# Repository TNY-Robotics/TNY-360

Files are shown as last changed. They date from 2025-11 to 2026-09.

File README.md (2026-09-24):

> 🚀 TNY-360 V2 launches October 1, 2026.
> 
> The repository will be updated with the V2 release files and documentation at launch.

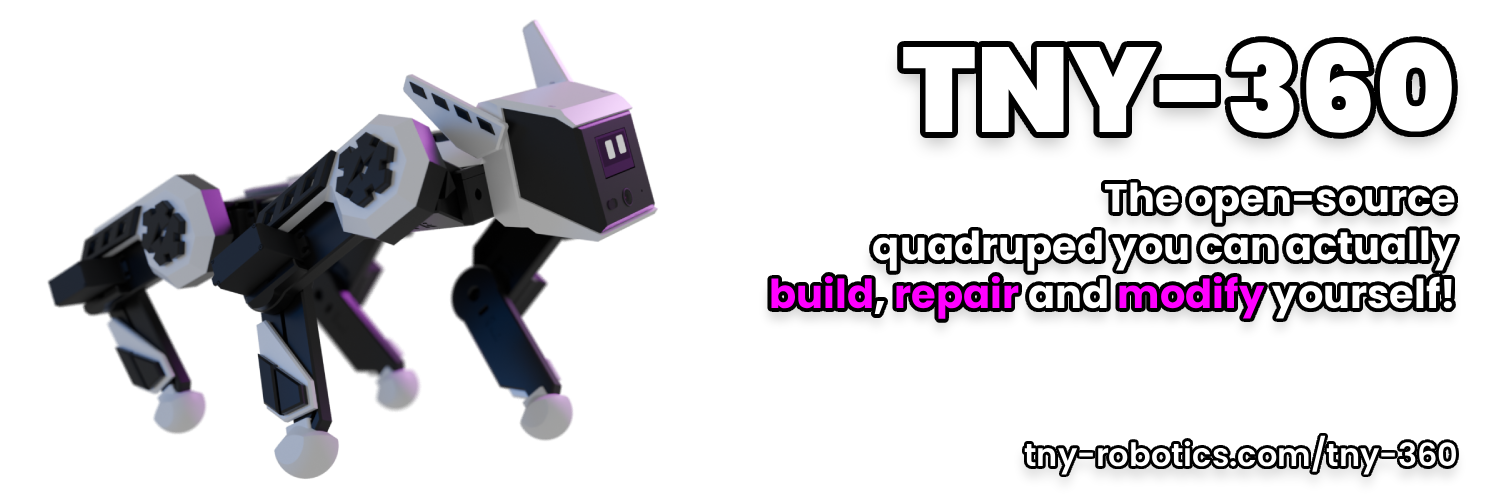
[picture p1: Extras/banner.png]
Banner


<div align="center">

# TNY-360 - Open-Source Robot Dog






**The open-source quadruped you can actually *build*, *repair* and *modify* yourself.**

[🌐 Website](https://tny-robotics.com/tny-360) • [📖 Documentation](https://tny-robotics.com/docs/tny-360/) • [💬 Discord](https://discord.gg/XGABkx5A4y) • [☕ Support Us](https://ko-fi.com/tnyrobotics)

</div>

<br />

# 🛠️ Want to build one?

<div align="center">

> ### **[👉 START HERE: The Official Step-by-Step Guide 👈](https://tny-robotics.com/docs/tny-360/practical-guide/sourcing)**
> *From ordering the first screw to assembling the last part, this guide covers it all.*

</div>

<br />

### 🗂️ Quick Links (For Advanced Makers)
If you know what you are doing and just want the raw files, here is your toolkit:

* 🛒 **[Bill of Materials (BOM)](https://tny-robotics.com/docs/tny-360/practical-guide/1.sourcing/)** - What to buy, tools needed, and where to find them.
* 📐 **[CAD & 3D Files](./CAD)** - Grab the `.STL` and `.3MF` files for your 3D printer.
* ⚡ **[PCB Designs (Gerbers)](./Electronics/PCBs)** - Files to order the custom PCBs used in the robot.
* 🧠 **[ESP32 Firmware](./Firmware)** - The ESP-IDF C++ firmware & drivers powering the robot.
* 🛠️ **[Servo Modding Tutorial](https://tny-robotics.com/docs/tny-360/anatomy/electronics/mg996r-mod)** - Learn the Op-Amp trick to get position-feedback on MG996R servos.

## ✨ Features

* 🧬 **Dual-Core Architecture:**<br> A segregated system using the ESP32-S3. Core 0 ("Reflex") runs a strict 200Hz kinematics/control loop, while Core 1 ("Brain") handles WebSockets, UI, and orchestration.
* 🔄 **Closed-Loop at 200Hz:**<br> We ditched blind PWM. The TNY-360 uses digital MG996R servos modified with a custom **Op-Amp buffer PCB** for noise-free, high-speed position feedback.
* ⚡ **Zero Cable Spaghetti:**<br> A fully modular hardware ecosystem. Dedicated PCBs (Control, Sensor, Brain, Power, etc.) communicate cleanly via standardized JST-PH cables.
* 🛠️ **Smart Auto-Calibration:**<br> Features mechanical endstops for assembly validation and runtime algorithms that compensate for backlash and actuator latency.
* 🧩 **STEM & Expansion Ready:**<br> Program the robot using [TNY-Coder](https://github.com/TNY-Robotics/TNY-Coder) (our block-based web app) or build custom hardware modules using the dorsal I2C/Power expansion port.
* 🔋 **Industrial Power:**<br> A custom 3S 18650 battery pack capable of 15A continuous discharge, featuring an integrated BMS and Fuse, for 1h+ of runtime.

## ⚙️ Hardware Specs

### 🧠 Core & Power
* **MCU:** ESP32-S3 N16R8 Module
* **Power:** 3S LiPo Battery (6x Samsung INR18650-25R)
* **Monitoring:** INA219 (Voltage/Current sensor)

### 🦵 Actuators
* **Legs:** 12x MG996R Servos *(Must be modified for analog feedback)*
* **Head:** 2x SG-90 Micro Servos (Ears)
* **Driver:** PCA9685 (16-Channel PWM)

### 📡 Sensors & I/O
* **Vision:** OV2640 Camera Module
* **Distance:** VL53L0X Time-of-Flight (Lidar)
* **Orientation:** MPU6050 6-axis IMU
* **Display:** SH1106 OLED (128x64)
* **Audio:** I2S MEMS Microphone + Speaker

---

## 📂 Repository Structure

* `BOM/` — **Bill of Materials.** Detailed lists of all components, PCBs, screws, and cables, with links.
* `CAD/` — **Hardware Source.** FreeCAD project files and ready-to-print STLs.
* `Electronics/PCBs/` — **PCB Designs.** Gerber files, BOMs, and Pick'n'Place for all PCBs.
* `Firmware/` — **Codebase.** PlatformIO project (C++/ESP-IDF).
* `Firmware/components/` — **Drivers.** Custom libraries for sensors/actuators.

## ☕ Support the Project

TNY-360 is, and will always be, 100% free and open-source. 

If you love the project, learned something new, or just want to help us build the next generation of affordable robots, consider supporting our R&D! Your tips help us buy prototyping materials (filament, PCBs, burned servos 😅) and keep the servers running.



*(Even if you can't donate, simply starring this repository or sharing it with a friend is already a massive support!)*

## 🤝 Contributing

We love contributions!
* **Code:** Please follow the ESP-IDF coding style.
* **Hardware:** Submit PRs with updated FreeCAD files or improvements.
* Found a bug? [Open an Issue](https://github.com/TNY-Robotics/TNY-360/issues).

## 📄 License & Authors

**TNY-360** is maintained by the [TNY Robotics Team](https://tny-robotics.com).

Licensed under **CC BY-NC-SA 4.0**.<br>
*You are free to share and adapt this material for non-commercial purposes, as long as you provide attribution and share alike.*



Need help? Contact us [by mail](mailto:contact@tny-robotics.com) or join our [Discord](https://discord.gg/XGABkx5A4y).

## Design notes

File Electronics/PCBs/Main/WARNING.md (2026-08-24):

# Warning : Inverted Diode

The D3 diode (between the fuse and the USB-C connector) is inverted in the schematics and the PCB.

Do not solder the diode, or place it "upside-down" to avoid any problem.

*sorry for the inconvenience, V2 of the robot is coming soon to fix this problem*

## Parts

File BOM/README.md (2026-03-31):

# Bill Of Material

Here's the raw List of components you need to build your own TNY-360 robot.

You can also find a more user-friendly version of this list on the [TNY-360 Documentation](https://tny-robotics.com/docs/tny-360/practical-guide/sourcing/) as well as guides and manuals to help you source, print, assemble, and set up your TNY-360!

- List of [Screws and Inserts](./Screws.md)

- List of [Cables](./Cables.md)

- List of [PCBs](./PCBs.md)

- List of [Components](./Components.md)

*Have fun building your robot!*

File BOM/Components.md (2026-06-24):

# Components

Here's a list of all the components needed to build your TNY-360, and their links!

### Assembly guide

To learn how to fully assemble you TNY-360, check out the [TNY-360 Documentation](http://tny-robotics.com/docs/tny-360/practical-guide/sourcing/). A more user-friendly list of all the components needed is also available here. 

| Type | Description | Quantity | Location | Link |
| :--- | :--- | :---: | :--- | :--- |
| Step down | DC-DC 300W 20A Buck Converter | 1 | Torso Back | [Click here](https://s.click.aliexpress.com/e/_c3atP8dn) |
| Step down | DC-DC 5V 3A Converter | 1 | Mount PCB | [Click here](https://fr.aliexpress.com/item/1005008678729834.html) \[5V\] |
| | | | | |
| VL53L0X | Laser depth sensor | 1 | Visor | [Click here](https://s.click.aliexpress.com/e/_c4LPbeMT) \[0-200CM\] |
| SH1106 | OLED Screen 64x128 | 1 | Visor | [Click here](https://s.click.aliexpress.com/e/_c4POAdYX) \[WHITE\] |
| TTP223 | Touch sensor | 2 | Visor | [Click here](https://fr.aliexpress.com/item/1005006087171183.html) |
| OV2640 | HD Camera  120° 75mm | 1 | Visor | [Click here](https://s.click.aliexpress.com/e/_c3eXa4EP) \[120°/75mm\] |
| I2S Mic.  | I2S Microphone | 1 | Visor | [Click here](https://s.click.aliexpress.com/e/_c3CFAo5V) |
| Speaker | 2W 8Ω Speaker (25mm x 35mm) | 1 | Head | [Click here](https://fr.aliexpress.com/item/1005008626624201.html) \[5PCS 8Ω 2W\] |
| | | | | |
| SG90 | 0.9kg.cm servomotor | 2 | Head | [Click here](https://s.click.aliexpress.com/e/_c4PiVQKP) \[180°\] |
| MG996R | 12kg.cm servomotor | 12 | Torso / Legs | [Click here](https://s.click.aliexpress.com/e/_c3QXPU2f) \[180°\] |
| | | | | |
| MPU6050 | 6 axis accelerometer & gyroscope | 1 | Torso Center | [Click here](https://s.click.aliexpress.com/e/_c4LXGDrH) |
| Switches  | Tactile switches 6x6x5 mm | 4 | Feet | [Click here](https://s.click.aliexpress.com/e/_c4koO1EL) \[6x6x5mm\] |
| Antenna | Wi-Fi/Bluetooth 2.4Ghz antenna | 1 | Head | [Click here](https://s.click.aliexpress.com/e/_c3wCvBLz) \[FPC-IPX1/5cm] |

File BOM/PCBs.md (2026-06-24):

# PCBs

Here's a list of all PCBs needed to build your TNY-360. You can find all design files in the [GitHub repository](https://github.com/TNY-Robotics/TNY-360/tree/main/Electronics/PCBs).

### Assembly guide

To learn how to fully assemble you TNY-360, check out the [TNY-360 Documentation](http://tny-robotics.com/docs/tny-360/practical-guide/sourcing/). A more user-friendly list of all the PCBs needed is also available here.

### PCBs list

| PCB | Purpose | Quantity | Files |
| --- | --- | :---: | --- |
| Main Board | Robot brain and main controller | 1 | [GitHub PCB Files](https://github.com/TNY-Robotics/TNY-360/tree/main/Electronics/PCBs/Main) |
| Analog Reader | Sensor interface board | 1 | [GitHub PCB Files](https://github.com/TNY-Robotics/TNY-360/tree/main/Electronics/PCBs/Analog%20Reader) |
| Motor Driver  | Motor control board | 1 | [GitHub PCB Files](https://github.com/TNY-Robotics/TNY-360/tree/main/Electronics/PCBs/Motor%20Driver) |
| Power Board | Power distribution | 1 | [GitHub PCB Files](https://github.com/TNY-Robotics/TNY-360/tree/main/Electronics/PCBs/Power) |
| Paw Board | Legs multiplexing and power management | 2 | [GitHub PCB Files](https://github.com/TNY-Robotics/TNY-360/tree/main/Electronics/PCBs/Paw) |
| Plug Board | Universal Mount interface | 1 | [GitHub PCB Files](https://github.com/TNY-Robotics/TNY-360/tree/main/Electronics/PCBs/Universal%20Mount) |
| Servo Board | Custom MG996R servo modification board | 12 | [GitHub PCB Files](https://github.com/TNY-Robotics/TNY-360/tree/main/Electronics/PCBs/Servomotor) |

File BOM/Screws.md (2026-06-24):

# Screws & Inserts

Here's a list of all screws and inserts needed to build your TNY-360.

A complete kit of M2.5 Screws and Inserts is also linked below for easier sourcing, instead of buying each screws/inserts independently.

### Assembly guide

To learn how to fully assemble you TNY-360, check out the [TNY-360 Documentation](http://tny-robotics.com/docs/tny-360/practical-guide/sourcing/). A more user-friendly list of all the screws and inserts needed is also available here.

### Screws 

| Type | Length | Quantity | Location | Link |
| :--- | :----- | :---: | :--- | :---: |
| M1.4 | 5 mm | 32 | Shoulder & Knee Servo Disk  | [Click here](https://s.click.aliexpress.com/e/_c3CWv1Vp) |
| | | | | |
| M2.5 | 4 mm | 2 | Torso - PCB Motor Driver | [Click here](https://s.click.aliexpress.com/e/_c3p0AJO3) |
| M2.5 | 4 mm | 2 | Torso - PCB Analog Reader | [Click here](https://s.click.aliexpress.com/e/_c3p0AJO3) |
| M2.5 | 4 mm | 2 | Torso - PCB IMU | [Click here](https://s.click.aliexpress.com/e/_c3p0AJO3) |
| M2.5 | 4 mm | 2 | Torso - PCB Paw Boards | [Click here](https://s.click.aliexpress.com/e/_c3p0AJO3) |
| M2.5 | 4 mm | 4 | Torso - DC-DC Converter | [Click here](https://s.click.aliexpress.com/e/_c3p0AJO3) |
| M2.5 | 10 mm  | 12 | Torso - Top / Bottom screws | [Click here](https://s.click.aliexpress.com/e/_c3p0AJO3) |
| M2.5 | 6 mm | 4 | Torso - Front | [Click here](https://s.click.aliexpress.com/e/_c3p0AJO3) |
| M2.5 | 6 mm | 4 | Torso - Back | [Click here](https://s.click.aliexpress.com/e/_c3p0AJO3) |
| M2.5 | 6 mm | 4 | Torso - Battery | [Click here](https://s.click.aliexpress.com/e/_c3p0AJO3) |
| | | | | |
| M2.5 | 4 mm | 4 | Head - Top | [Click here](https://s.click.aliexpress.com/e/_c3p0AJO3) |
| M2.5 | 4 mm | 4 | Head - Bottom | [Click here](https://s.click.aliexpress.com/e/_c3p0AJO3) |
| M2.5 | 4 mm | 2 | Head - Face Plate | [Click here](https://s.click.aliexpress.com/e/_c3p0AJO3) |
| M2.5 | 4 mm | 4 | Head - PCB | [Click here](https://s.click.aliexpress.com/e/_c3p0AJO3) |
| | | | | |
| M2.5 | 6 mm | 8 | Shoulders - Top | [Click here](https://s.click.aliexpress.com/e/_c3p0AJO3) |
| M2.5 | 4 mm | 2 | Ears - Main Screw | [Click here](https://s.click.aliexpress.com/e/_c3p0AJO3) |
| M2.5 | 4 mm | 3 | Back - PCB | [Click here](https://s.click.aliexpress.com/e/_c3p0AJO3) |
| M2.5 | 4 mm | 4 | Back - Cover | [Click here](https://s.click.aliexpress.com/e/_c3p0AJO3) |
| | | | | |
| M2.5 | 6 mm | 4 | Mount - Cover | [Click here](https://s.click.aliexpress.com/e/_c3p0AJO3) |
| M2.5 | 6 mm | 4 | Mount - Attachment | [Click here](https://s.click.aliexpress.com/e/_c3p0AJO3) |
| M2.5 | 4 mm | 2 | Mount - PCB | [Click here](https://s.click.aliexpress.com/e/_c3p0AJO3) |
| | | | | |
| M2.5 | 4 mm | 6 | Battery - PCB | [Click here](https://s.click.aliexpress.com/e/_c3p0AJO3) |
| M2.5 | 4 mm | 6 | Battery - Cover | [Click here](https://s.click.aliexpress.com/e/_c3p0AJO3) |

### Inserts 

| Type | Length | Quantity | Location | Link |
| :--- | :----- | :---: | :--- | :---: |
| M2.5 | 2 mm | 2 | Torso - PCB Motor Driver | [Click here](https://fr.aliexpress.com/item/1005007653131713.html) |
| M2.5 | 2 mm | 2 | Torso - PCB Analog Reader | [Click here](https://fr.aliexpress.com/item/1005007653131713.html) |
| M2.5 | 2 mm | 2 | Torso - PCB IMU | [Click here](https://fr.aliexpress.com/item/1005007653131713.html) |
| M2.5 | 2 mm | 2 | Torso - PCB Paw Boards | [Click here](https://fr.aliexpress.com/item/1005007653131713.html) |
| M2.5 | 2 mm | 4 | Torso - DC-DC Converter | [Click here](https://fr.aliexpress.com/item/1005007653131713.html) |
| M2.5 | 6 mm | 12 | Torso - Top / Bottom screws | [Click here](https://fr.aliexpress.com/item/1005007653131713.html) |
| M2.5 | 4 mm | 4 | Torso - Front | [Click here](https://fr.aliexpress.com/item/1005007653131713.html) |
| M2.5 | 4 mm | 4 | Torso - Back | [Click here](https://fr.aliexpress.com/item/1005007653131713.html) |
| M2.5 | 2 mm | 4 | Torso - Battery | [Click here](https://fr.aliexpress.com/item/1005007653131713.html) |
| | | | | |
| M2.5 | 2 mm | 4 | Head - Top | [Click here](https://fr.aliexpress.com/item/1005007653131713.html) |
| M2.5 | 2 mm | 4 | Head - Bottom | [Click here](https://fr.aliexpress.com/item/1005007653131713.html) |
| M2.5 | 2 mm | 2 | Head - Face Plate | [Click here](https://fr.aliexpress.com/item/1005007653131713.html) |
| M2.5 | 2 mm | 4 | Head - PCB | [Click here](https://fr.aliexpress.com/item/1005007653131713.html) |
| | | | | |
| M2.5 | 2 mm | 8 | Shoulders - Top | [Click here](https://fr.aliexpress.com/item/1005007653131713.html) |
| M2.5 | 2 mm | 2 | Ears - Main Screw | [Click here](https://fr.aliexpress.com/item/1005007653131713.html) |
| M2.5 | 2 mm | 3 | Back - PCB | [Click here](https://fr.aliexpress.com/item/1005007653131713.html) |
| M2.5 | 2 mm | 4 | Back - Cover | [Click here](https://fr.aliexpress.com/item/1005007653131713.html) |
| | | | | |
| M2.5 | 4 mm | 4 | Mount - Cover | [Click here](https://fr.aliexpress.com/item/1005007653131713.html) |
| M2.5 | 4 mm | 4 | Mount - Attachment | [Click here](https://fr.aliexpress.com/item/1005007653131713.html) |
| M2.5 | 2 mm | 2 | Mount - PCB | [Click here](https://fr.aliexpress.com/item/1005007653131713.html) |
| | | | | |
| M2.5 | 2 mm | 6 | Battery - PCB | [Click here](https://fr.aliexpress.com/item/1005007653131713.html) |
| M2.5 | 2 mm | 6 | Battery - Cover | [Click here](https://fr.aliexpress.com/item/1005007653131713.html) |

### Total 

| Type | Quantity | Link |
| :--- | :---: | --- |
| M1.4 Screw - 5 mm  | 32 | [Click here](https://s.click.aliexpress.com/e/_c3CWv1Vp) |
| | | |
| M2.5 Screw - 4 mm  | 49 | [Click here](https://s.click.aliexpress.com/e/_c3p0AJO3) |
| M2.5 Screw - 6 mm  | 28 | [Click here](https://s.click.aliexpress.com/e/_c3p0AJO3) |
| M2.5 Screw - 10 mm | 12 | [Click here](https://s.click.aliexpress.com/e/_c3p0AJO3) |
| | | |
| M2.5 Insert - 2 mm | 61 | [Click here](https://fr.aliexpress.com/item/1005007653131713.html) |
| M2.5 Insert - 4 mm | 16 | [Click here](https://fr.aliexpress.com/item/1005007653131713.html) |
| M2.5 Insert - 6 mm | 12 | [Click here](https://fr.aliexpress.com/item/1005007653131713.html) |

### Complete kit

To simplify Screws and Inserts sourcing, you can alternatively buy only one complete kit of M2.5 screws and inserts.

* Link to the [Screws / Inserts Kit](https://fr.aliexpress.com/item/1005007830491580.html).

Please check that you selected the `M2.5 500pcs` version before ordering.

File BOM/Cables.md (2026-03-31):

# Cables

Here's a list of all cables needed to wire up your TNY-360.

A complete kit of JST-PH wires is also linked below for easier sourcing, instead of buying each cable independently.

### Assembly guide

To learn how to fully assemble you TNY-360, check out the [TNY-360 Documentation](https://tny-robotics.com/docs/tny-360/practical-guide/sourcing/). A more user-friendly list of all the cables needed is also available here.

| Type | Pins | Length | Quantity | Location | Link |
| :--- | :--: | :----- | :---: | :--- | :--- |
| JST-PH |  3 | 100 mm | 4 | Motor Driver -> Paw Board | [Click here](https://s.click.aliexpress.com/e/_c3BIp6Ux) |
| JST-PH |  2 | 100 mm | 1 | Motor Driver -> Main Board | [Click here](https://s.click.aliexpress.com/e/_c3BIp6Ux) |
| JST-PH |  5 | 100 mm | 1 | Motor Driver -> Main Board | [Click here](https://s.click.aliexpress.com/e/_c3BIp6Ux) |
| JST-PH |  4 | 100 mm | 4 | Analog Reader -> Paw Board | [Click here](https://s.click.aliexpress.com/e/_c3BIp6Ux) |
| JST-PH |  7 | 100 mm | 1 | Analog Reader -> Main Board | [Click here](https://s.click.aliexpress.com/e/_c3BIp6Ux) |
| JST-PH (PIGTAIL) |  4 | 200 mm | 1 | IMU -> Paw Board | [Click here](https://s.click.aliexpress.com/e/_c44pILQb) |
| JST-PH |  4 | 200 mm | 2 | Plug Board -> Power & Main Board | [Click here](https://s.click.aliexpress.com/e/_c3BIp6Ux) |
| JST-PH |  2 | 200 mm | 2 | Plug Board -> Power & Main Board | [Click here](https://s.click.aliexpress.com/e/_c3BIp6Ux) |
| JST-PH (PIGTAIL) |  4 | 50 mm  | 1 | SH1106 -> Main Board | [Click here](https://s.click.aliexpress.com/e/_c44pILQb) |
| JST-PH (PIGTAIL) |  3 | 50 mm  | 2 | TTP23 -> Main Board | [Click here](https://s.click.aliexpress.com/e/_c44pILQb) |
| JST-PH (PIGTAIL) |  4 | 50 mm  | 1 | VL53L0X -> Main Board | [Click here](https://s.click.aliexpress.com/e/_c44pILQb) |
| JST-PH (PIGTAIL) |  5 | 50 mm  | 1 | I2S Mic. -> Main Board | [Click here](https://s.click.aliexpress.com/e/_c44pILQb) |
| JST-PH (PIGTAIL) |  2 | 450 mm | 4 | Contact Switch -> Paw Board | [Click here](https://s.click.aliexpress.com/e/_c44pILQb) |
| JST-XH (PIGTAIL) |  4 | 100 mm | 8 | Shoulder Servo -> Paw Board | [Click here](https://s.click.aliexpress.com/e/_c3WRxkg7) |
| JST-XH (PIGTAIL) |  4 | 300 mm | 4 | Leg Servo -> Paw Board | [Click here](https://s.click.aliexpress.com/e/_c3WRxkg7) |
| JST-XH (PIGTAIL) |  4 | 300 mm | 4 | Leg Servo -> Paw Board | [Click here](https://s.click.aliexpress.com/e/_c3WRxkg7) |
| 16 AWG Wire | | 100 mm | 3 | DC-DC Converter -> Paw Board | [Click here](https://fr.aliexpress.com/item/1005006614755156.html) |

### Connectors
| Type | Quantity | Link |
| --- | --- | --- |
| Ring Crimp Connector | 6 | [Click here](https://s.click.aliexpress.com/e/_c2yxJCd5) |
| Dupont Connector | 4 | None - Use the ones from the MG996R motors :) |

### Complete kit

To simplify cable sourcing, you can alternatively buy only one JST-PH cable kit, and some JST-XH pigtail cables.

* Link to the [JST-PH Cables Kit](https://s.click.aliexpress.com/e/_c3AtPZ9h).
* Link to the [Dupont Connector Kit](https://fr.aliexpress.com/item/4001063470283.html);
* Link to the [JST-XH Pigtail Cables](https://s.click.aliexpress.com/e/_c3WRxkg7).

Please check that you selected the `XH-2.54mm version (4P)` before ordering.

### About the SH1106, TTP23, VL53L0X and I2S Mic. cables

Since these cables are going to be soldered directly on the component, you can buy a 100mm cable and cut it in half to make 2x 50mm pigtail cables. This reduces the number of cables to order.

### About the contact switch cable

The contact switch cable should end with a 3-pin Dupont connector (the standard 2.54mm arduino connectors), with the middle pin empty.

No such cable (JST-PH 2-Pins to 2.54 mm Dupont 3 Pins) exists on the web, so you will probably have to make it yourself. A complete guide on how to create that cable is available *(or will be available)* on the [TNY-360 Documentation](https://tny-robotics.com/docs/tny-360).

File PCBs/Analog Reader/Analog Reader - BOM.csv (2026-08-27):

No. | Quantity | Comment | Designator | Footprint | Value | Manufacturer Part | Manufacturer | Supplier Part | Supplier
1 | 1 | 74HC4067PW,118 | 74HC4067 | TSSOP-24_L7.8-W4.4-P0.65-LS6.4-BL |  | 74HC4067PW,118 | Nexperia(安世) | C179326 | LCSC
2 | 1 | HX PZ2.0-2x5P TP | BRAIN | CONN-SMD_HX-PZ2.0-2X5P-TP |  | HX PZ2.0-2x5P TP | hanxia(韩下) | C32713243 | LCSC
3 | 16 | 1uF | C1,C2,C3,C4,C5,C6,C7,C8,C9,C10,C11,C12,C13,C14,C15,C16 | C0603 | 1uF | CL10A105KB8NNNC | SAMSUNG(三星) | C15849 | LCSC
4 | 2 | 100nF | C-74HC1,C-OPA1 | C0603 | 100nF | CC0603KRX7R9BB104 | YAGEO(国巨) | C14663 | LCSC
5 | 1 | XL-0807RGBC-2812B | LED | LED-SMD_4P-L2.0-W1.8_XL-0807RGBC-WS2812B |  | XL-0807RGBC-2812B | XINGLIGHT(成兴光) | C3646929 | LCSC
6 | 2 | HX PZ2.0-2x4P TP | LEFT,RIGHT | CONN-SMD_HX-PZ2.0-2X4P-TP |  | HX PZ2.0-2x4P TP | hanxia(韩下) | C32713242 | LCSC
7 | 1 | AD8628ARTZ(UMW) | OP-AMP1 | SOT-23-5_L2.9-W1.6-P0.95-LS2.8-BR |  | AD8628ARTZ(UMW) | UMW(友台半导体) | C32713098 | LCSC
8 | 16 | 1kΩ | R1,R2,R3,R4,R5,R6,R7,R8,R9,R10,R11,R12,R13,R14,R15,R16 | R0603 | 1kΩ | 0603WAF1001T5E | UNI-ROYAL(厚声) | C21190 | LCSC
9 | 1 | 220Ω | ROPA1 | R0603 | 220Ω | 0603WAF2200T5E | UNI-ROYAL(厚声) | C22962 | LCSC

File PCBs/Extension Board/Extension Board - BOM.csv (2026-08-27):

No. | Quantity | Comment | Designator | Footprint | Value | Manufacturer Part | Manufacturer | Supplier Part | Supplier
1 | 1 | ZX-PH2.0-LT4P | EXT | CONN-SMD_4P-P2.00_MEGASTAR_ZX-PH2.0-LT4P |  | ZX-PH2.0-LT4P | Megastar(兆星) | C7429700 | LCSC
2 | 1 | ZX-PHB2.0-2-3PLT | POWER | CONN-SMD_6P-P2.00_ZX-PHB2.0-2-3PLT |  | ZX-PHB2.0-2-3PLT | Megastar(兆星) | C19078801 | LCSC
3 | 1 | 1kΩ | R1 | R0603 | 1kΩ | 0603WAF1001T5E | UNI-ROYAL(厚声) | C21190 | LCSC
4 | 1 | AMS1117-3.3 | U1 | SOT-223-3_L6.5-W3.4-P2.30-LS7.0-BR |  | AMS1117-3.3 | Advanced Monolithic Systems | C6186 | LCSC

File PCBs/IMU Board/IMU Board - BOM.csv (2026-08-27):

No. | Quantity | Comment | Designator | Footprint | Value | Manufacturer Part | Manufacturer | Supplier Part | Supplier
1 | 1 | PZ200-2-04-S | BRAIN | HDR-SMD_8P-P2.00-V-M-R2-C4-LS6.5_PZ200-2-04-S |  | PZ200-2-04-S | HCTL(华灿天禄) | C3294483 | LCSC
2 | 2 | 100nF | C1,C2 | C0603 | 100nF | CC0603KRX7R9BB104 | YAGEO(国巨) | C14663 | LCSC
3 | 1 | XL-0807RGBC-2812B | LED | LED-SMD_4P-L2.0-W1.8_XL-0807RGBC-WS2812B |  | XL-0807RGBC-2812B | XINGLIGHT(成兴光) | C3646929 | LCSC
4 | 1 | LSM6DSLTR | LSM6DS3 | LGA-14_L3.0-W2.5-P0.50-TL |  | LSM6DSLTR | ST(意法半导体) | C126672 | LCSC

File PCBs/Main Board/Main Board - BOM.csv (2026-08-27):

No. | Quantity | Comment | Designator | Footprint | Value | Manufacturer Part | Manufacturer | Supplier Part | Supplier
1 | 2 | AMS1117-3.3 | AMS3.3,AMS3.3ESP | SOT-223-3_L6.5-W3.4-P2.30-LS7.0-BR |  | AMS1117-3.3 | Advanced Monolithic Systems | C6186 | LCSC
2 | 1 | AFA07-S14FCA-00 | BACKBONE | FPC-SMD_P1.00-14P_LCS-XJ-H2.5 |  | AFA07-S14FCA-00 | JS(钜硕电子) | C262720 | LCSC
3 | 2 | 1nF | C1,C2 | C0603 | 1nF | CL10B102KB8NNNC | SAMSUNG(三星) | C1588 | LCSC
4 | 2 | 1uF | C3,CUPEN | C0603 | 1uF | CL10A105KB8NNNC | SAMSUNG(三星) | C15849 | LCSC
5 | 1 | 470uF | C4 | CAP-SMD_BD6.3-L6.6-W6.6-FD | 470uF | RVT1A471M0607 | ROQANG(容强) | C335982 | LCSC
6 | 7 | 100nF | CA,CAVDD1,CB,CCAM14,CCSI-RST,CDVDD1,CESP1 | C0603 | 100nF | CC0603KRX7R9BB104 | YAGEO(国巨) | C14663 | LCSC
7 | 1 | FPC-05F-24PH20 | CAMERA | FPC-SMD_24P-P0.50_FPC-05F-24PH20 |  | FPC-05F-24PH20 | XUNPU(讯普) | C2856805 | LCSC
8 | 1 | 10nF | CASIG | C0603 | 10nF | 0603B103K500NT | FH(风华) | C57112 | LCSC
9 | 4 | 10uF | CAVDD2,CCH340,CDVDD2,CESP2 | C0603 | 10uF | CL10A106MA8NRNC | SAMSUNG(三星) | C96446 | LCSC
10 | 1 | 15pF | CCAM8 | C0603 | 15pF | CL10C150JB8NNNC | SAMSUNG(三星) | C1644 | LCSC
11 | 1 | CH340C | CH340C | SOP-16_L10.0-W3.9-P1.27-LS6.0-BL |  | CH340C | WCH(南京沁恒) | C84681 | LCSC
12 | 2 | SS34 | D1,D2 | SMA_L4.3-W2.6-LS5.2-RD |  | SS34 | MDD(辰达半导体) | C8678 | LCSC
13 | 1 | ESP32-S3-WROOM-1U-N16R8 | ESP32-S3 | WIRELM-SMD_ESP32-S3-WROOM-1U |  | ESP32-S3-WROOM-1U-N16R8 | ESPRESSIF(乐鑫) | C3013946 | LCSC
14 | 2 | BLM18PG121SN1D | L1,L2 | L0603 |  | BLM18PG121SN1D | muRata(村田) | C14709 | LCSC
15 | 1 | XL-0807RGBC-2812B | LED | LED-SMD_4P-L2.0-W1.8_XL-0807RGBC-WS2812B |  | XL-0807RGBC-2812B | XINGLIGHT(成兴光) | C3646929 | LCSC
16 | 1 | NS4168 | NS4168 | ESOP-8_L4.9-W3.9-P1.27-LS6.0-BL-EP |  | NS4168 | Nsiway(纳芯威) | C910588 | LCSC
17 | 2 | S8050 J3Y(RANGE:200-350) | QDTR1,QRTS1 | SOT-23-3_L3.0-W1.7-P0.95-LS2.9-BR |  | S8050 J3Y(RANGE:200-350) | CJ(江苏长电/长晶) | C2146 | LCSC
18 | 4 | 10kΩ | R1,RDTR1,RRTS1,RUPEN | R0603 | 10kΩ | 0603WAF1002T5E | UNI-ROYAL(厚声) | C25804 | LCSC
19 | 1 | 1kΩ | RCAM17 | R0603 | 1kΩ | 0603WAF1001T5E | UNI-ROYAL(厚声) | C21190 | LCSC
20 | 1 | 33Ω | RMIC | R0603 | 33Ω | 0603WAF330JT5E | UNI-ROYAL(厚声) | C23140 | LCSC
21 | 1 | 4.7kΩ | RRST | R0603 | 4.7kΩ | 0603WAF4701T5E | UNI-ROYAL(厚声) | C23162 | LCSC
22 | 4 | 2.2kΩ | RUPFA,RUPFL,RUPSA,RUPSL | R0603 | 2.2kΩ | 0603WAF2201T5E | UNI-ROYAL(厚声) | C4190 | LCSC
23 | 2 | 5.1kΩ | RUSB1,RUSB2 | R0402 | 5.1kΩ | 0402WGF5101TCE | UNI-ROYAL(厚声) | C25905 | LCSC
24 | 1 | HC-1.25-2PWT | SPKR | CONN-SMD_2P-P1.25-HC-1.25-2PWT |  | HC-1.25-2PWT | HCTL(华灿天禄) | C2845379 | LCSC
25 | 2 | TS-1088-AR02016 | SW_0,SW_EN | SW-SMD_L3.9-W3.0-P4.45 |  | TS-1088-AR02016 | XUNPU(讯普) | C720477 | LCSC
26 | 1 | TXB0104RUTR | TXB0104 | UQFN-12_L2.0-W1.7-P0.40-BL |  | TXB0104RUTR | TI(德州仪器) | C105266 | LCSC
27 | 1 | TYPE-C16PIN | USB | USB-C-SMD_TYPE-C16PIN |  | TYPE-C16PIN | SHOU HAN(首韩) | C393939 | LCSC
28 | 1 | USBLC6-2SC6 | USBLC6 | SOT-23-6_L2.9-W1.6-P0.95-LS2.8-BL |  | USBLC6-2SC6 | ST(意法半导体) | C7519 | LCSC
29 | 1 | AFA07-S08FCA-00 | VISOR | FPC-SMD_8P-P1.00_LCS-XJ |  | AFA07-S08FCA-00 | JS(钜硕电子) | C262714 | LCSC
30 | 1 | XC6206-1.2V | XC6206-1.2 | SOT-23-3_L3.0-W1.6-P1.90-LS2.8-BR |  | XC6206-1.2V | YONGYUTAI(永裕泰) | C49446790 | LCSC
31 | 1 | XC6206-2.8V | XC6206-2.8 | SOT-23-3_L2.9-W1.6-P1.90-LS2.8-BR |  | XC6206-2.8V | YONGYUTAI(永裕泰) | C2892669 | LCSC

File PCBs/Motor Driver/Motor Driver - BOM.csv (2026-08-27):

No. | Quantity | Comment | Designator | Footprint | Value | Manufacturer Part | Manufacturer | Supplier Part | Supplier
1 | 3 | HX PZ2.0-2x4P TP | BRAIN,LEFT,RIGHT | CONN-SMD_HX-PZ2.0-2X4P-TP |  | HX PZ2.0-2x4P TP | hanxia(韩下) | C32713242 | LCSC
2 | 2 | 100nF | CLS1,CPCA1 | C0603 | 100nF | CC0603KRX7R9BB104 | YAGEO(国巨) | C14663 | LCSC
3 | 1 | XL-0807RGBC-2812B | LED | LED-SMD_4P-L2.0-W1.8_XL-0807RGBC-WS2812B |  | XL-0807RGBC-2812B | XINGLIGHT(成兴光) | C3646929 | LCSC
4 | 1 | PCA9306DCUR | PCA9306 | SSOP-8_L2.0-W2.3-P0.50-LS3.1-BR |  | PCA9306DCUR | TI(德州仪器) | C33196 | LCSC
5 | 1 | PCA9685PW,118 | PCA9685 | TSSOP-28_L9.7-W4.4-P0.65-LS6.4-TL | - | PCA9685PW,118 | NXP(恩智浦) | C2678753 | LCSC
6 | 16 | 220Ω | R1,R2,R3,R4,R5,R6,R7,R8,R9,R10,R11,R12,R13,R14,R15,R16 | R0603 | 220Ω | 0603WAF2200T5E | UNI-ROYAL(厚声) | C22962 | LCSC
7 | 1 | 200kΩ | R-LS1 | R0603 | 200kΩ | 0603WAF2003T5E | UNI-ROYAL(厚声) | C25811 | LCSC
8 | 2 | 2.2kΩ | RUP1,RUP2 | R0603 | 2.2kΩ | 0603WAF2201T5E | UNI-ROYAL(厚声) | C4190 | LCSC

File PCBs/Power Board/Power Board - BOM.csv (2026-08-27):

No. | Quantity | Comment | Designator | Footprint | Value | Manufacturer Part | Manufacturer | Supplier Part | Supplier
1 | 1 | XT60PB-M.G.Y | BAT | CONN-TH_XT60PB-M |  | XT60PB-M.G.Y | AMASS(艾迈斯) | C19268037 | LCSC
2 | 1 | 1uF | C1 | C0603 | 1uF | CL10A105KB8NNNC | SAMSUNG(三星) | C15849 | LCSC
3 | 1 | XF-508PVS-B | F1 | FUSE-SMD_4P-L16.0-W6.7-P9.92 |  | XF-508PVS-B | XFCN(兴飞) | C17700142 | LCSC
4 | 1 | WAFER-PH2.0-2PLB | I2C | CONN-TH_2P-P2.00_XUNPU_WAFER-PH2.0-2PLB |  | WAFER-PH2.0-2PLB | XUNPU(讯普) | C3029431 | LCSC
5 | 1 | INA219BIDR | INA219 | SOIC-8_L5.0-W4.0-P1.27-LS6.1-BL |  | INA219BIDR | TI(德州仪器) | C2155799 | LCSC
6 | 1 | 78L05G-AB3-R | LDO | SOT-89-3_L4.5-W2.5-P1.50-LS4.2-BR |  | 78L05G-AB3-R | UTC(友顺) | C71136 | LCSC
7 | 1 | XT30UPB-F30.G.Y | OUT | CONN-TH_XT30UPB-F |  | XT30UPB-F30.G.Y | AMASS(艾迈斯) | C108769 | LCSC
8 | 2 | LWP3005AD5 | Q1,Q2 | TDSON-8_L5.9-W5.2-P1.27-BL-1 |  | LWP3005AD5 | Lewa Micro(乐瓦微电子) | C54740917 | LCSC
9 | 1 | 100kΩ | R1 | R0603 | 100kΩ | 0603WAF1003T5E | UNI-ROYAL(厚声) | C25803 | LCSC
10 | 1 | 10kΩ | R2 | R0603 | 10kΩ | 0603WAF1002T5E | UNI-ROYAL(厚声) | C25804 | LCSC
11 | 1 | 2mΩ | Rsns | R2512 | 2mΩ | FRM252WFR002TN | FOJAN(富捷) | C7467245 | LCSC
12 | 1 | MST-12D18G4 SPDT Slide Switch | SW | SW-SMD_MST-12D18G4-SPDT-SLIDE-SWITCH |  | MST-12D18G4 SPDT Slide Switch | SHOU HAN(首韩) | C49023767 | LCSC

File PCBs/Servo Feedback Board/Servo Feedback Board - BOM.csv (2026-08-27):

No. | Quantity | Comment | Designator | Footprint | Value | Manufacturer Part | Manufacturer | Supplier Part | Supplier
1 | 1 | 100nF | C1 | C0402 | 100nF | CL05B104KO5NNNC | SAMSUNG(三星) | C1525 | LCSC
2 | 1 | AD8628ARTZ(UMW) | OP-AMP | SOT-23-5_L2.9-W1.6-P0.95-LS2.8-BR |  | AD8628ARTZ(UMW) | UMW(友台半导体) | C32713098 | LCSC

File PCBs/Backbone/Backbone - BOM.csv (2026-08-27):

No. | Quantity | Comment | Designator | Footprint | Value | Manufacturer Part | Manufacturer | Supplier Part | Supplier
1 | 1 | HX PM2.0-2x5P TP | AR | HDR-SMD_10P-P2.00-V-F-R2-C5-LS6.2-1 |  | HX PM2.0-2x5P TP | hanxia(韩下) | C41397150 | LCSC
2 | 6 | HX PM2.0-2x4P TP | AR-L,AR-R,IMU,MD,MD-L,MD-R | HDR-SMD_HX-PM2.0-2X4P-TP |  | HX PM2.0-2x4P TP | hanxia(韩下) | C41397149 | LCSC
3 | 12 | WAFER-XH2.54-4PLB | BL-HP,BL-HR,BL-KP,BR-HP,BR-HR,BR-KP,FL-HP,FL-HR,FL-KP,FR-HP,FR-HR,FR-KP | CONN-SMD_4P-P2.50_XUNPU_WAFER-XH2.54-4PLB |  | WAFER-XH2.54-4PLB | XUNPU(讯普) | C3029469 | LCSC
4 | 4 | WAFER-SH1.0-3PLB | BL-SW,BR-SW,FL-SW,FR-SW | CONN-SMD_3P-P1.00_XUNPU_WAFER-SH1.0-3PLB |  | WAFER-SH1.0-3PLB | XUNPU(讯普) | C3029333 | LCSC
5 | 1 | AFA07-S14FCC-00 | BRAIN | FPC-SMD_P1.00-14P_LCS-XJ-H2.5 |  | AFA07-S14FCC-00 | JS(钜硕电子) | C262348 | LCSC
6 | 3 | 1000uF | C1,C2,C3 | CAP-SMD_BD8.0-L8.3-W8.3-LS9.1-FD | 1000uF | RVT1000UF10V34RV0081 | KNSCHA(科尼盛) | C2904875 | LCSC
7 | 3 | 100nF | C5,C6,CLS1 | C0603 | 100nF | CC0603KRX7R9BB104 | YAGEO(国巨) | C14663 | LCSC
8 | 1 | 470uF | C7 | CAP-SMD_BD6.3-L6.6-W6.6-FD | 470uF | RVT1A471M0607 | ROQANG(容强) | C335982 | LCSC
9 | 1 | 100nF | C8 | C0402 | 100nF | CL05B104KO5NNNC | SAMSUNG(三星) | C1525 | LCSC
10 | 1 | 10uF | C9 | C0402 | 10uF | CL05A106MQ5NUNC | SAMSUNG(三星) | C15525 | LCSC
11 | 2 | WAFER-PH2.0-3PLB | EAR-L,EAR-R | CONN-SMD_3P-P2.00_XUNPU_WAFER-PH2.0-3PLB |  | WAFER-PH2.0-3PLB | XUNPU(讯普) | C3029432 | LCSC
12 | 1 | WAFER-PH2.0-4PLB | EXT-PCB | CONN-SMD_4P-P2.00_WAFER-200L-4A |  | WAFER-PH2.0-4PLB | XUNPU(讯普) | C3029433 | LCSC
13 | 1 | HX PM2.54-1x4P TP-YQ | I2C | HDR-SMD_HX-PM2.54-1X4P-TP-YQ |  | HX PM2.54-1x4P TP-YQ | hanxia(韩下) | C42379197 | LCSC
14 | 1 | WAFER-PH2.0-2PLB | INA | CONN-TH_2P-P2.00_XUNPU_WAFER-PH2.0-2PLB |  | WAFER-PH2.0-2PLB | XUNPU(讯普) | C3029431 | LCSC
15 | 1 | HX PM2.54-1x3P TP-YQ | LED | HDR-SMD_3P-P2.54-V-F_C9900045551 |  | HX PM2.54-1x3P TP-YQ | hanxia(韩下) | C42379196 | LCSC
16 | 1 | PCA9306DCUR | PCA9306 | SSOP-8_L2.0-W2.3-P0.50-LS3.1-BR |  | PCA9306DCUR | TI(德州仪器) | C33196 | LCSC
17 | 1 | XT30PW-M20.G.Y | PW-MTR | XT30-TH_XT30PW-M20.G.Y |  | XT30PW-M20.G.Y | AMASS(艾迈斯) | C30170175 | LCSC
18 | 1 | HC-PM254-5.0H-2x3PS-02A | PWM | CONN-SMD_HC-PM254-5.0H-2X3PS-02A |  | HC-PM254-5.0H-2x3PS-02A | HC(虹成电子) | C42163131 | LCSC
19 | 1 | 200kΩ | R-LS1 | R0603 | 200kΩ | 0603WAF2003T5E | UNI-ROYAL(厚声) | C25811 | LCSC
20 | 2 | 2.2kΩ | RUP1,RUP2 | R0603 | 2.2kΩ | 0603WAF2201T5E | UNI-ROYAL(厚声) | C4190 | LCSC
21 | 2 | HC-1.0-4PLT | STMQT1,STMQT2 | CONN-SMD_4P-P1.00_HC-1.0-4PLT |  | HC-1.0-4PLT | HCTL(华灿天禄) | C2845372 | LCSC

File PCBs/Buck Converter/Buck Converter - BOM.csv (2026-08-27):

No. | Quantity | Comment | Designator | Footprint | Value | Manufacturer Part | Manufacturer | Supplier Part | Supplier
1 | 3 | 10uF | C1,C2,Cin | C0603 | 10uF | CL10A106MA8NRNC | SAMSUNG(三星) | C96446 | LCSC
2 | 3 | 100nF | Cboot,Cboot1,Coutx | C0402 | 100nF | CL05B104KB54PNC | SAMSUNG(三星) | C307331 | LCSC
3 | 2 | 820pF | Ccomp1,Cramp | C0402 | 820pF | CL05C821JB5NNNC | SAMSUNG(三星) | C307452 | LCSC
4 | 1 | 47pF | Ccomp2 | C0402 | 47pF | 0402CG470J500NT | FH(风华) | C1567 | LCSC
5 | 4 | 22uF | Cin1,Cin2,Cin3,Cin4 | C1210 | 22uF | GMK325BJ226MM-P | TAIYO YUDEN(太诱) | C778721 | LCSC
6 | 1 | 220nF | Cinx | C0603 | 220nF | CL10B224KA8NNNC | SAMSUNG(三星) | C21120 | LCSC
7 | 1 | 100nF | Cinx1 | C0805 | 100nF | CL21B104KCFNNNE | SAMSUNG(三星) | C28233 | LCSC
8 | 1 | XT30PW-M20.G.Y | CN1 | XT30-TH_XT30PW-M20.G.Y |  | XT30PW-M20.G.Y | AMASS(艾迈斯) | C30170175 | LCSC
9 | 3 | 330uF | Cout1,Cout2,Cout3 | CAP-SMD_BD6.3-L6.6-W6.6-LS7.3-FD | 330uF | 16SVPG330M | PANASONIC(松下) | C1850459 | LCSC
10 | 3 | 47uF | Cout4,Cout5,Cout6 | C1210 | 47uF | GRM32ER61C476KE15L | muRata(村田) | C77101 | LCSC
11 | 2 | 470nF | Cres,Cvcc | C0603 | 470nF | CL10B474KA8NNNC | SAMSUNG(三星) | C1623 | LCSC
12 | 1 | 22nF | Css | C0402 | 22nF | 0402B223K500NT | FH(风华) | C1532 | LCSC
13 | 1 | 1uF | Cvcc1 | C0402 | 1uF | CL05A105KA5NQNC | SAMSUNG(三星) | C52923 | LCSC
14 | 1 | BAT54WS | D1 | SOD-323_L1.7-W1.3-LS2.6-RD-1 |  | BAT54WS | R+O(宏嘉诚) | C7502694 | LCSC
15 | 1 | ZX-PHB2.0-2-3PLT | EXT | CONN-SMD_6P-P2.00_ZX-PHB2.0-2-3PLT |  | ZX-PHB2.0-2-3PLT | Megastar(兆星) | C19078801 | LCSC
16 | 1 | 2.2uH | L1 | IND-SMD_L17.0-W17.0_GDIM1770-101MTF | 2.2uH | GDIM1770-2R2MTF | GUDIAN(固电) | C49237942 | LCSC
17 | 1 | 8.2uH | L2 | IND-SMD_L7.0-W6.6_FXL0630 | 8.2uH | FXL0630-8R2-M | cjiang(长江微电) | C167222 | LCSC
18 | 1 | LM5117PMHX/NOPB | LM5117 | HTSSOP-20_L6.5-W4.4-P0.65-LS6.4-BL-EP |  | LM5117PMHX/NOPB | TI(德州仪器) | C390088 | LCSC
19 | 2 | NTMFS5C442NT1G | M1,M2 | DFN-5_L4.9-W5.9-P1.27-LS6.2-BL |  | NTMFS5C442NT1G | onsemi(安森美) | C464094 | LCSC
20 | 1 | XT30PW-F20.G.Y | OUT | CONN-TH_XT30PW-F-1 |  | XT30PW-F20.G.Y | AMASS(艾迈斯) | C2913282 | LCSC
21 | 1 | 51kΩ | Rcomp | R0402 | 51kΩ | 0402WGF5102TCE | UNI-ROYAL(厚声) | C25794 | LCSC
22 | 1 | 1kΩ | Rfb1 | R0603 | 1kΩ | 0603WAF1001T5E | UNI-ROYAL(厚声) | C21190 | LCSC
23 | 1 | 7.5kΩ | Rfb2 | R0603 | 7.5kΩ | 0603WAF7501T5E | UNI-ROYAL(厚声) | C23234 | LCSC
24 | 1 | 24kΩ | Rfbb | R0603 | 24kΩ | 0603WAF2402T5E | UNI-ROYAL(厚声) | C23352 | LCSC
25 | 2 | 100kΩ | Rfbt,Rfbt1 | R0402 | 100kΩ | 0402WGF1003TCE | UNI-ROYAL(厚声) | C25741 | LCSC
26 | 1 | 75kΩ | Rramp | R0603 | 75kΩ | 0603WAF7502T5E | UNI-ROYAL(厚声) | C23242 | LCSC
27 | 1 | 3mΩ | Rsense | R2512 | 3mΩ | HoYLR2512-3W-3mR-1% | Milliohm(毫欧) | C5375459 | LCSC
28 | 1 | 12kΩ | Rt | R0402 | 12kΩ | 0402WGF1202TCE | UNI-ROYAL(厚声) | C25752 | LCSC
29 | 1 | 10kΩ | Ruv1 | R0603 | 10kΩ | 0603WAF1002T5E | UNI-ROYAL(厚声) | C25804 | LCSC
30 | 1 | 56kΩ | Ruv2 | R0603 | 56kΩ | 0603WAF5602T5E | UNI-ROYAL(厚声) | C23206 | LCSC
31 | 1 | LMR33630ADDAR | U1 | ESOP-8_L4.9-W3.9-P1.27-LS6.0-TL-EP |  | LMR33630ADDAR | TI(德州仪器) | C841384 | LCSC

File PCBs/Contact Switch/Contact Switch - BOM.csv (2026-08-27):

No. | Quantity | Comment | Designator | Footprint | Value | Manufacturer Part | Manufacturer | Supplier Part | Supplier
1 | 1 | 100nF | C1 | C0402 | 100nF | CL05B104KO5NNNC | SAMSUNG(三星) | C1525 | LCSC
2 | 1 | WAFER-SH1.0-3PLB | CN1 | CONN-SMD_3P-P1.00_XUNPU_WAFER-SH1.0-3PLB |  | WAFER-SH1.0-3PLB | XUNPU(讯普) | C3029333 | LCSC
3 | 1 | HAL49ESO | IC | SOT-23-3_L2.9-W1.6-P1.90-LS2.8-BR-CW |  | HAL49ESO | Hallwee(霍尔微电子) | C7420984 | LCSC
4 | 1 | 1kΩ | R1 | R0402 | 1kΩ | 0402WGF1001TCE | UNI-ROYAL(厚声) | C11702 | LCSC

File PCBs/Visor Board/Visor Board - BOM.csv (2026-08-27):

No. | Quantity | Comment | Designator | Footprint | Value | Manufacturer Part | Manufacturer | Supplier Part | Supplier
1 | 1 | AP3012KTR-G1 | AP3012 | TSOT-23-5_L2.9-W1.6-P0.95-LS2.8-BL |  | AP3012KTR-G1 | DIODES(美台) | C102618 | LCSC
2 | 1 | AFA07-S08FCA-00 | BRAIN | FPC-SMD_8P-P1.00_LCS-XJ |  | AFA07-S08FCA-00 | JS(钜硕电子) | C262714 | LCSC
3 | 2 | 10uF | C1,C3 | C0603 | 10uF | CL10A106KP8NNNC | SAMSUNG(三星) | C19702 | LCSC
4 | 6 | 100nF | C2,C4,C5,C6,C9,C11 | C0603 | 100nF | CC0603KRX7R9BB104 | YAGEO(国巨) | C14663 | LCSC
5 | 2 | 4.7uF | C7,C10 | C0603 | 4.7uF | CL10A475KO8NNNC | SAMSUNG(三星) | C19666 | LCSC
6 | 2 | 10uF | C8,C12 | C0603 | 10uF | CL10A106MA8NRNC | SAMSUNG(三星) | C96446 | LCSC
7 | 2 | 1uF | Cin,Cout | C0603 | 1uF | CL10A105KB8NNNC | SAMSUNG(三星) | C15849 | LCSC
8 | 1 | 1N5819WS | D1 | SOD-323_L1.7-W1.3-LS2.7-RD |  | 1N5819WS | Hottech(合科泰) | C191023 | LCSC
9 | 1 | 10uH | L1 | IND-SMD_L2.5-W2.0 | 10uH | FTC252012S100MBCA | cjiang(长江微电) | C5832376 | LCSC
10 | 1 | MSM261DHT006 | MSM261 | LGA-8_L4.0-W3.0-R_WMM7040DT0 |  | MSM261DHT006 | MEMS(敏芯微) | C51928215 | LCSC
11 | 2 | 1kΩ | R1,R2 | R0603 | 1kΩ | 0603WAF1001T5E | UNI-ROYAL(厚声) | C21190 | LCSC
12 | 1 | 10kΩ | R3 | R0603 | 10kΩ | 0603WAF1002T5E | UNI-ROYAL(厚声) | C25804 | LCSC
13 | 1 | 100Ω | R4 | R0603 | 100Ω | 0603WAF1000T5E | UNI-ROYAL(厚声) | C22775 | LCSC
14 | 1 | 470kΩ | R5 | R0603 | 470kΩ | 0603WAF4703T5E | UNI-ROYAL(厚声) | C23178 | LCSC
15 | 1 | 51kΩ | R6 | R0603 | 51kΩ | 0603WAF5102T5E | UNI-ROYAL(厚声) | C23196 | LCSC
16 | 1 | 1MΩ | R7 | R0603 | 1MΩ | 0603WAF1004T5E | UNI-ROYAL(厚声) | C22935 | LCSC
17 | 1 | 33Ω | RMIC | R0603 | 33Ω | 0603WAF330JT5E | UNI-ROYAL(厚声) | C23140 | LCSC
18 | 1 | FPC-05F-24PH20 | SCREEN | FPC-SMD_24P-P0.50_FPC-05F-24PH20 |  | FPC-05F-24PH20 | XUNPU(讯普) | C2856805 | LCSC
19 | 2 | RH6015C | TCH-L,TCH-R | SOT-23-6_L2.9-W1.6-P0.95-LS2.8-BR |  | RH6015C | RONGHE(融和) | C78180 | LCSC
20 | 1 | VL53L0CXV0DH/1 | VL53L0 | OPTO-SMD_12P_VL53L0CXV0DH-1 |  | VL53L0CXV0DH/1 | ST(意法半导体) | C91199 | LCSC

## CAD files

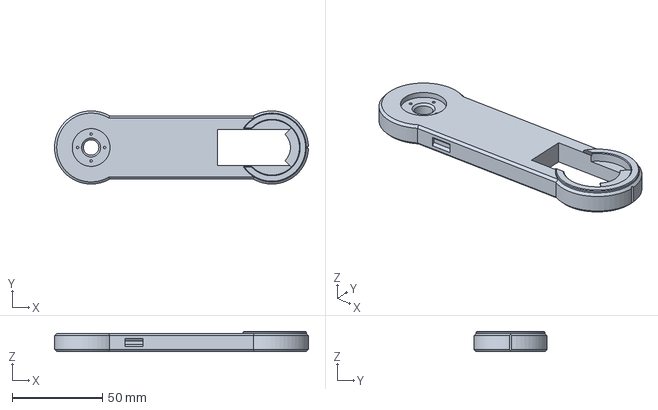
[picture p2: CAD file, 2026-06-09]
CAD/01_Parts/Leg_Top.FCStd
140.5 x 40.5 x 11.2 mm

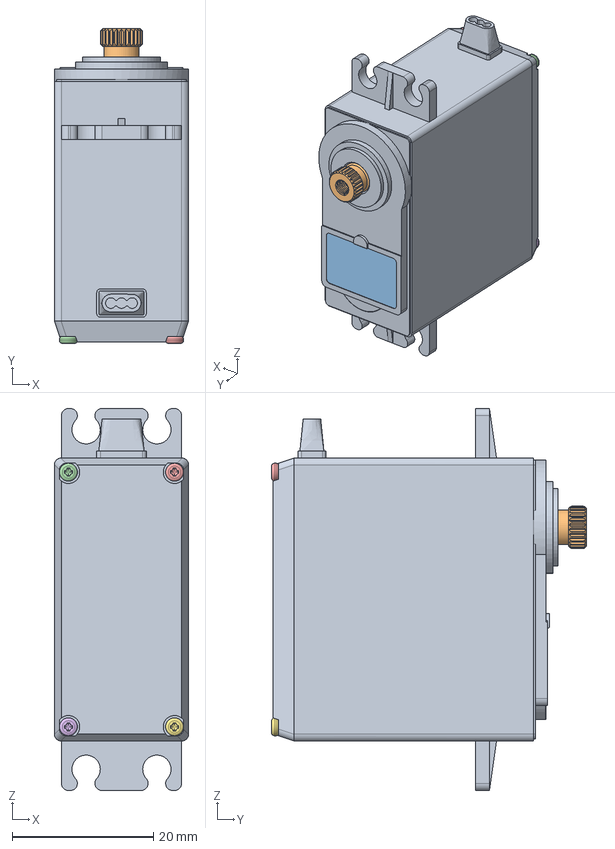
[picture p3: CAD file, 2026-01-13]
CAD/02_External/MG996R.FCStd
19.0 x 44.5 x 54.0 mm
MG996R v1
MG996R v002
MG996R v003
MG996R v004
MG996R v005
MG996R v006
MG996R v007

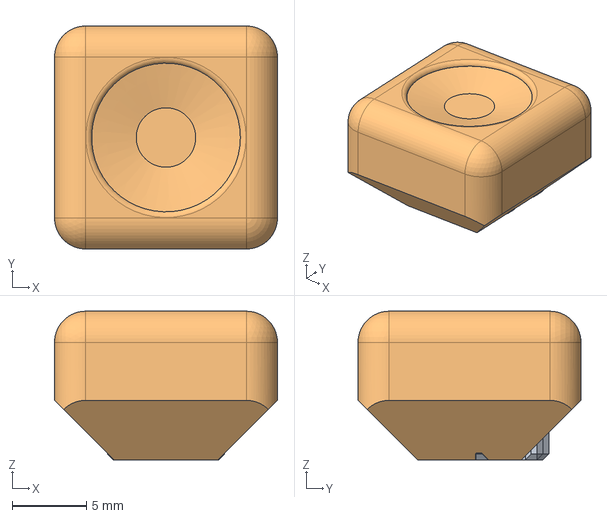
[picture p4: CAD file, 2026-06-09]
CAD/03_Common/Master_Clip.FCStd
15.0 x 15.0 x 10.0 mm
Clip
ClipHelper

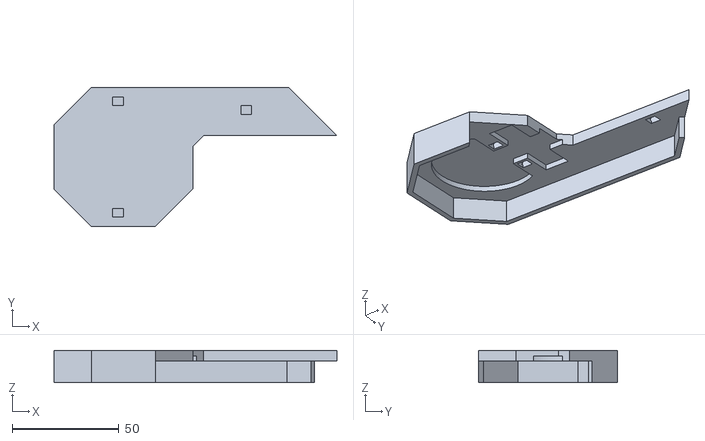
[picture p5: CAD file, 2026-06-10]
CAD/Exported/STLs/Leg - Top Cover Bottom L.stl
132.5 x 65.0 x 15.0

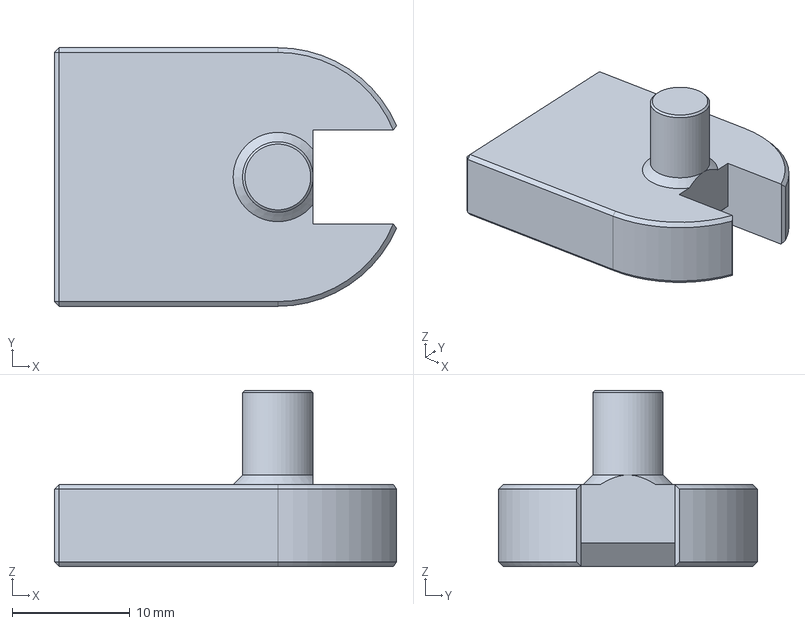
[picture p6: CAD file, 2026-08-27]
CAD/Servo Pin attach.FCStd
29.1 x 22.0 x 15.0 mm

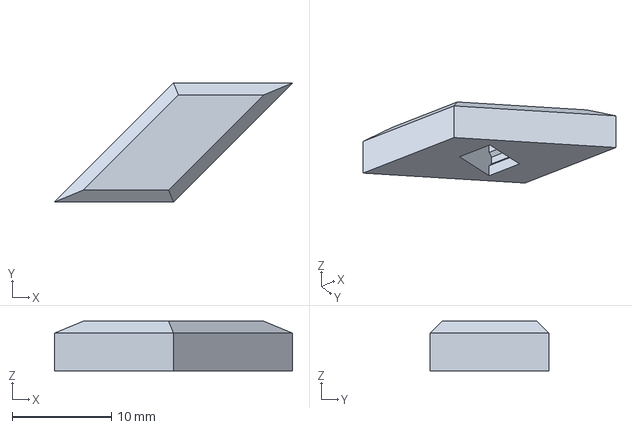
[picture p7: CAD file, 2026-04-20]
CAD/01_Parts/Torso.FCStd
24.0 x 12.0 x 5.00 mm

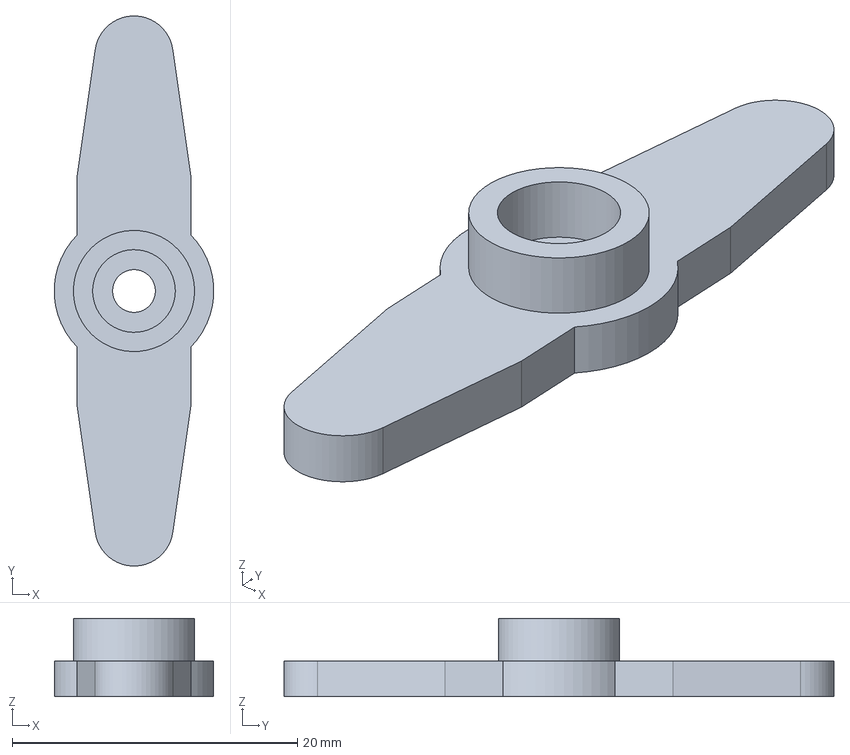
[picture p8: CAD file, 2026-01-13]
CAD/02_External/Servo Arm.FCStd
11.2 x 38.6 x 5.50 mm

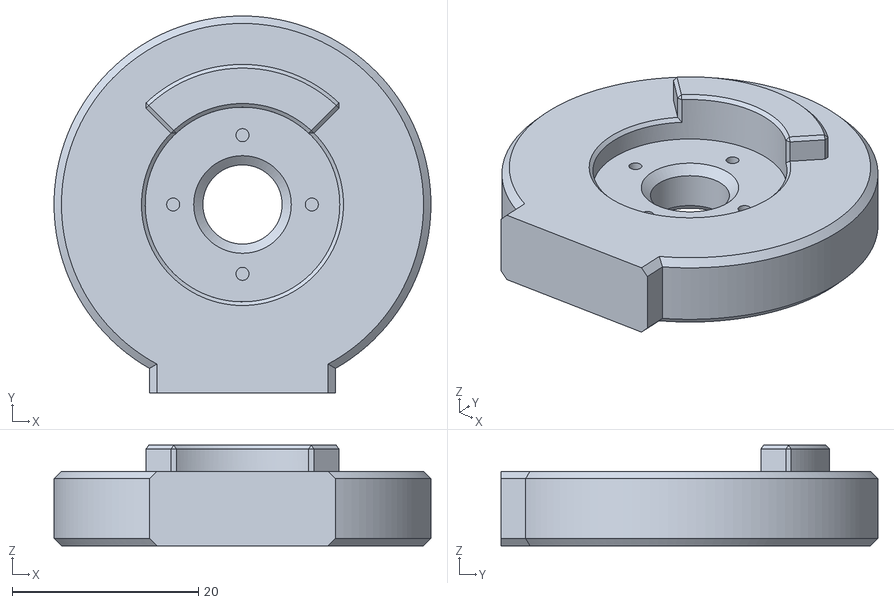
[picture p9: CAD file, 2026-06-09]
CAD/Exported/STLs/Settings - JointOuter.stl
40.5 x 40.5 x 10.8

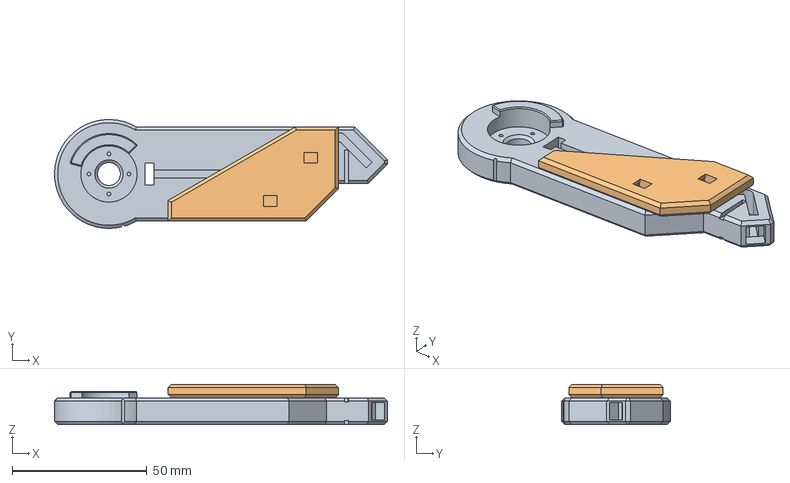
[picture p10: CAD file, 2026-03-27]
CAD/01_Parts/Leg_Bottom.FCStd
123.8 x 40.5 x 15.0 mm
Leg Bottom R - Template
Cover R

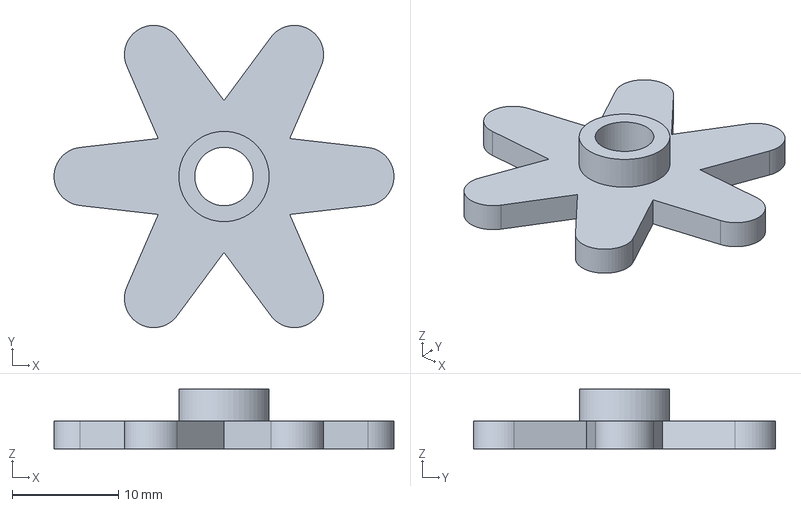
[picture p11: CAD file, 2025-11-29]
CAD/02_External/Servo Flower.FCStd
32.0 x 28.4 x 5.60 mm

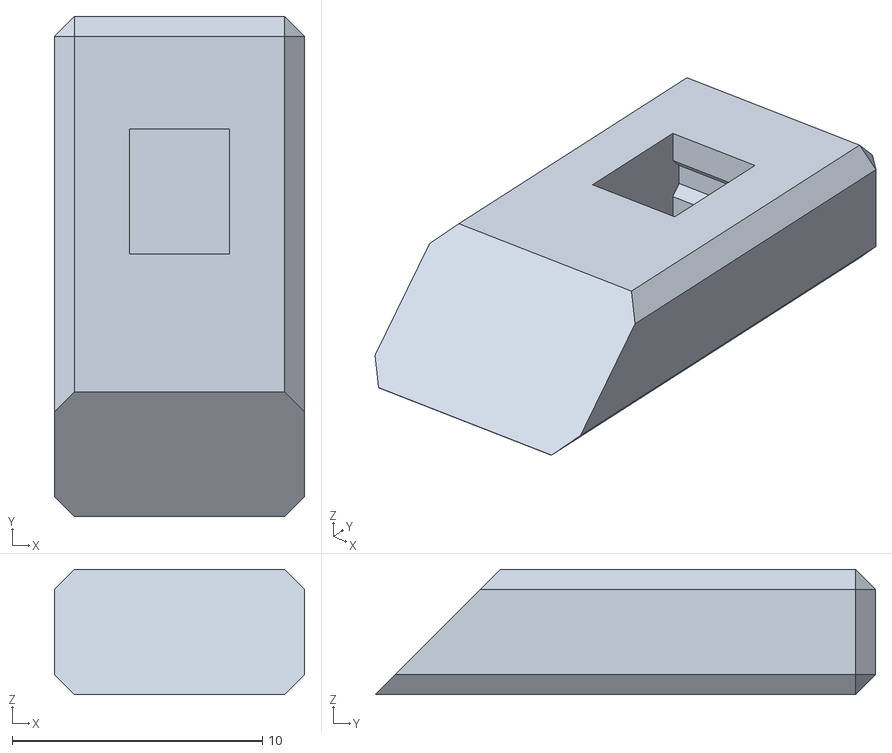
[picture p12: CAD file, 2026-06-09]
CAD/Exported/STLs/Settings - ClipTester.stl
10.0 x 20.0 x 5.00

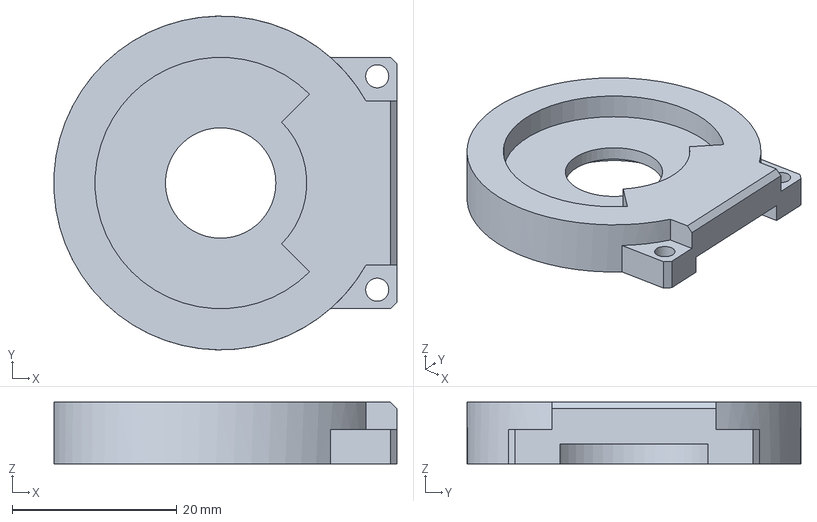
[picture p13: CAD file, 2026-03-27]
CAD/01_Parts/Shoulders.FCStd
41.6 x 40.5 x 7.50 mm

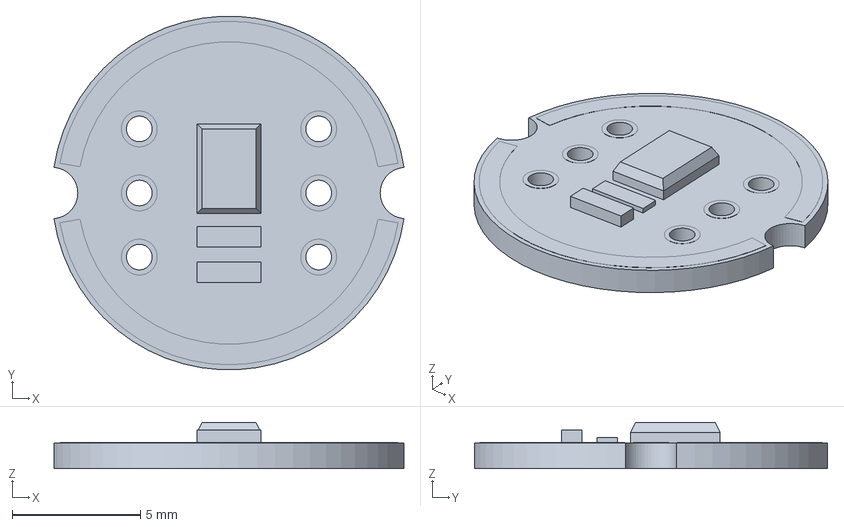
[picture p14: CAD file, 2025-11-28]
CAD/02_External/I2S Microphone Breakout Board.FCStd
13.7 x 13.8 x 1.81 mm

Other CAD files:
CAD/00_Assemblies/Test.FCStd
CAD/00_Assemblies/Ear_L.FCStd
CAD/Settings.FCStd
CAD/00_Assemblies/Ear_R.FCStd
CAD/Exported/STLs/Torso - Cover Wing R.stl
CAD/01_Parts/Battery Pack.FCStd
CAD/01_Parts/DC-DC Backplate.FCStd
CAD/01_Parts/DC-DC Frontplate.FCStd
CAD/01_Parts/Ears.FCStd
CAD/01_Parts/Head.FCStd
CAD/01_Parts/Servo_Cover_L.FCStd
CAD/01_Parts/Torso-Shoulder_Pin.FCStd
CAD/02_External/BMS 3S 20A.FCStd
CAD/02_External/DC-DC Buck 20A.FCStd
CAD/02_External/INR18650-25R.FCStd
CAD/02_External/MPU6050.FCStd
CAD/02_External/SG90.FCStd
CAD/02_External/TOF200C.FCStd
CAD/02_External/USB-C Charger 3S.FCStd
CAD/Exported/STLs/Back - Bottom Clip.stl
CAD/Exported/STLs/Back - Cover.stl
CAD/Exported/STLs/Battery - LipoHolder Base.stl
CAD/Exported/STLs/Clip - Helper.stl
CAD/Exported/STLs/Clip.stl
CAD/Exported/STLs/Ears - Back L.stl
CAD/Exported/STLs/Ears - Back R.stl
CAD/Exported/STLs/Ears - Deco L.stl
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

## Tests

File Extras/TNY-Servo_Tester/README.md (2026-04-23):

# TNY-Servo Tester

This project is for people building their own TNY Servomotors.

It provides a simple way to ensure the servomotors work correctly before they are installed in the robot.

---

> [!NOTE]  
> The code is dirty. It is not meant to be used as a reference for good coding practices, but rather as a quick and dirty solution to test the servomotors.

## Hardware

The tester is made to work on an ESP32-S3 Dev Board, here's the pinout:

| ESP32-S3 Pin | Function |
| --- | --- |
| GPIO 48 | LED Control (WS2812) |
| GPIO 42 | Servo Signal (PWM) |
| GPIO 02 | Servo Feedback (ADC1_CH1) |

While powering up a motor from the ESP32-S3 Dev Board is not recommended, it's acceptable to power the servo from the board's **5V** & **GND** pins for testing purposes. The servo will only draw a small amount of current during the test (as long as you don't block its movement), so it should be safe to power it from the board.

For easier testing, connect a 4-Pin Dupont 2.54mm header to the ESP32-S3 Dev Board, and then connect the TNY-Servo's JST-XH connector to the header. This will allow you to easily connect and disconnect the servo for testing.

> [!WARNING]  
> Make sure to connect the **GROUND** pin of the servo first (slightly tilt the connector when plugging it in) to avoid damaging the servo or the ESP32-S3 Dev Board. If power is applied to the servo before the ground connection is made, it can cause the current to come back through the servo's internal circuitry. 

## Software

The code is written in C++ using the ESP-IDF framework. It uses the LEDC peripheral to generate the PWM signal for the servo and the ADC to read the feedback from the servo.

## Usage

1. Connect the servo to the ESP32-S3 Dev Board according to the pinout above.
2. Power on or reset the ESP32-S3 Dev Board.
3. Wait for the code to run and observe the LED color and the servo movement.
4. For more detailed information on the test, check the serial output using a serial monitor.

### Testing sequence

The testing sequence is simple :
1. The servo will move to its minimum position (0°) and wait a little bit for the ADC reading to stabilize.
2. The servo will then move to its maximum position (180°) and wait again for the ADC reading to stabilize.
3. Finally, the servo will move back to its center position (90°) and wait for the ADC reading to stabilize.

At the end of the test, the code will check if the ADC readings are within the expected range, noise & order for the servo to be considered working correctly. Even if the servo is moving during the test, the feedback could still be incorrect, so wait for the test to finish and check the LED color to know if the servo is fully functional or not.

### LED Color Indication

While testing, the LED will display in **BLUE**. This indicates that the tester is running and the servo is being tested.

At the end of the test, the LED will change to **GREEN** if the servo is working correctly, or **RED** if there is an issue with the servo.

For more information on the test results, check the serial output.

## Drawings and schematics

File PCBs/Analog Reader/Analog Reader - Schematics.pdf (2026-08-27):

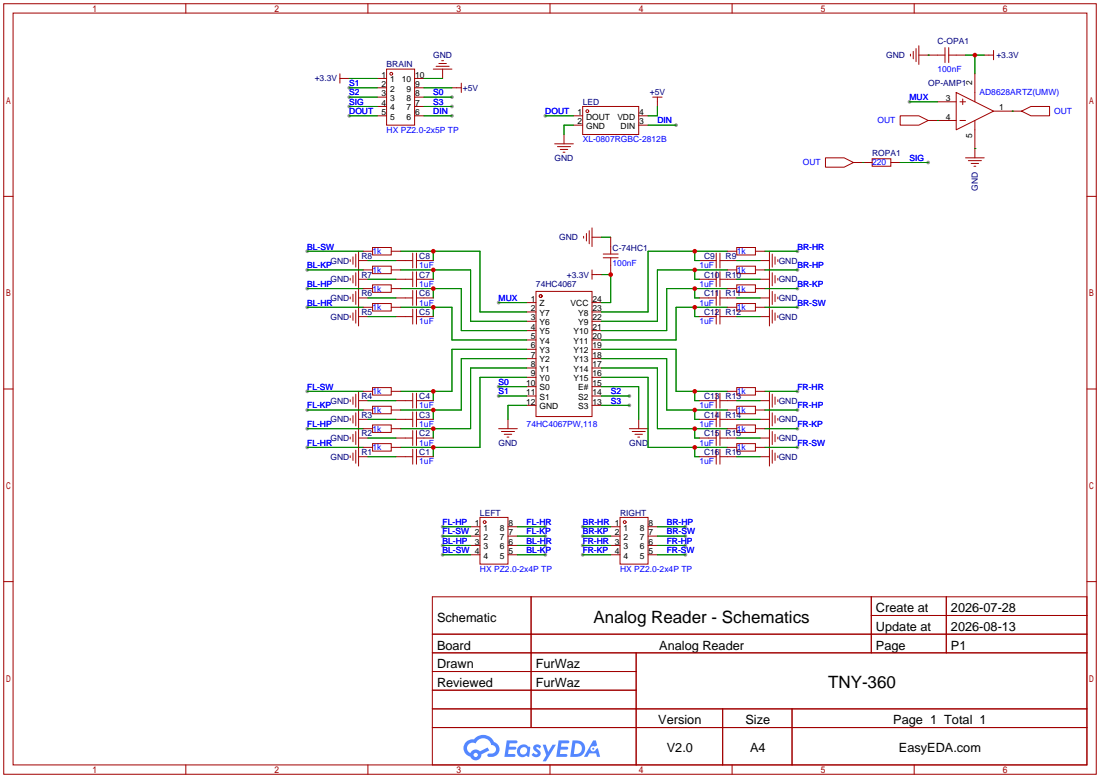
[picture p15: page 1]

Schematic | Analog Reader - Schematics | Create at | 2026-07-28

Update at | 2026-08-13

Board | Analog Reader | Page | P1
Drawn | FurWaz | TNY-360
Reviewed | FurWaz

Version | Size | Page 1 Total 1
V2.0 | A4 | EasyEDA.com

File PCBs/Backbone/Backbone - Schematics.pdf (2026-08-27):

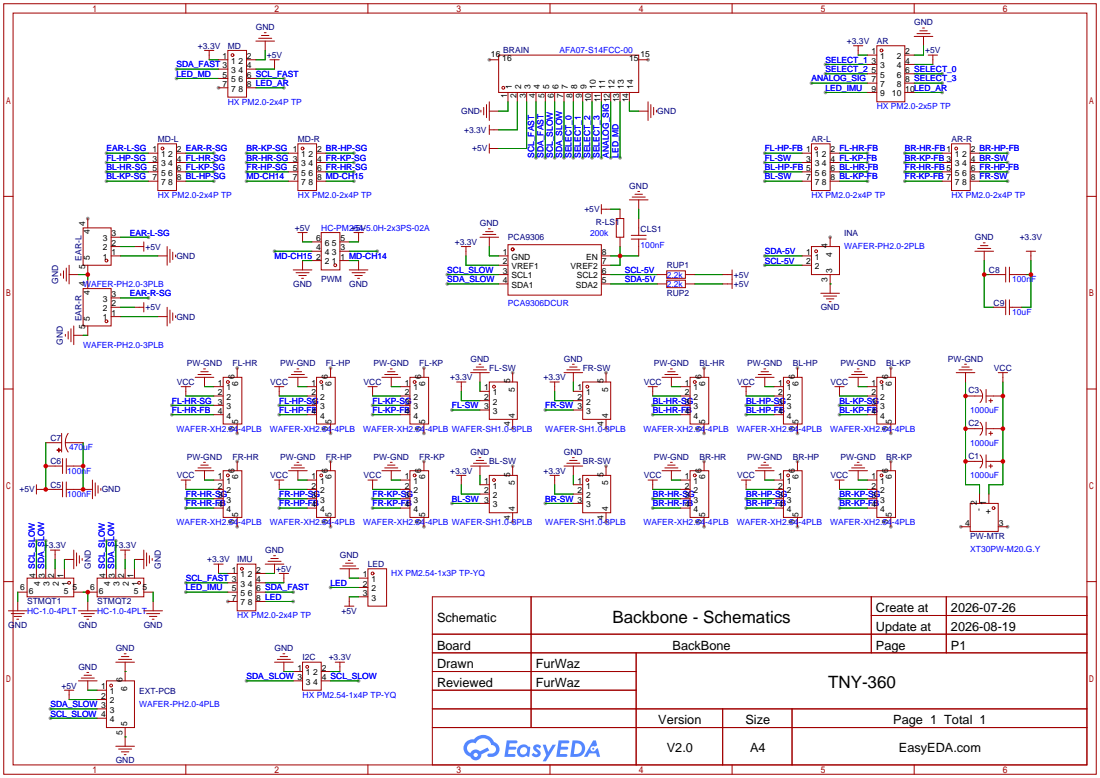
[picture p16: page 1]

Schematic | Backbone - Schematics | Create at | 2026-07-26

Update at | 2026-08-19

Board | BackBone | Page | P1
Drawn | FurWaz | TNY-360
Reviewed | FurWaz

Version | Size | Page 1 Total 1
V2.0 | A4 | EasyEDA.com

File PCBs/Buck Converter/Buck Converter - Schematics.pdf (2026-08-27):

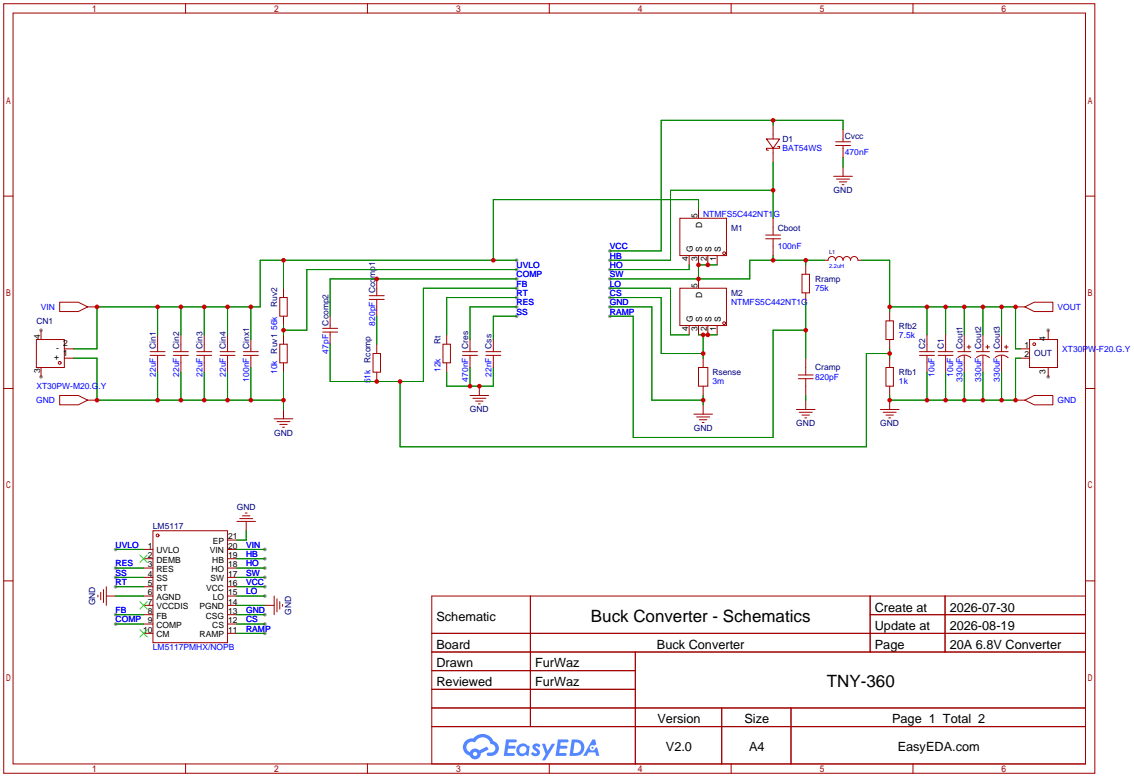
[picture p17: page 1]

Schematic | Buck Converter - Schematics | Create at | 2026-07-30

Update at | 2026-08-19

Board | Buck Converter | Page | 20A 6.8V Converter
Drawn | FurWaz | TNY-360
Reviewed | FurWaz

Version | Size | Page 1 Total 2
V2.0 | A4 | EasyEDA.com

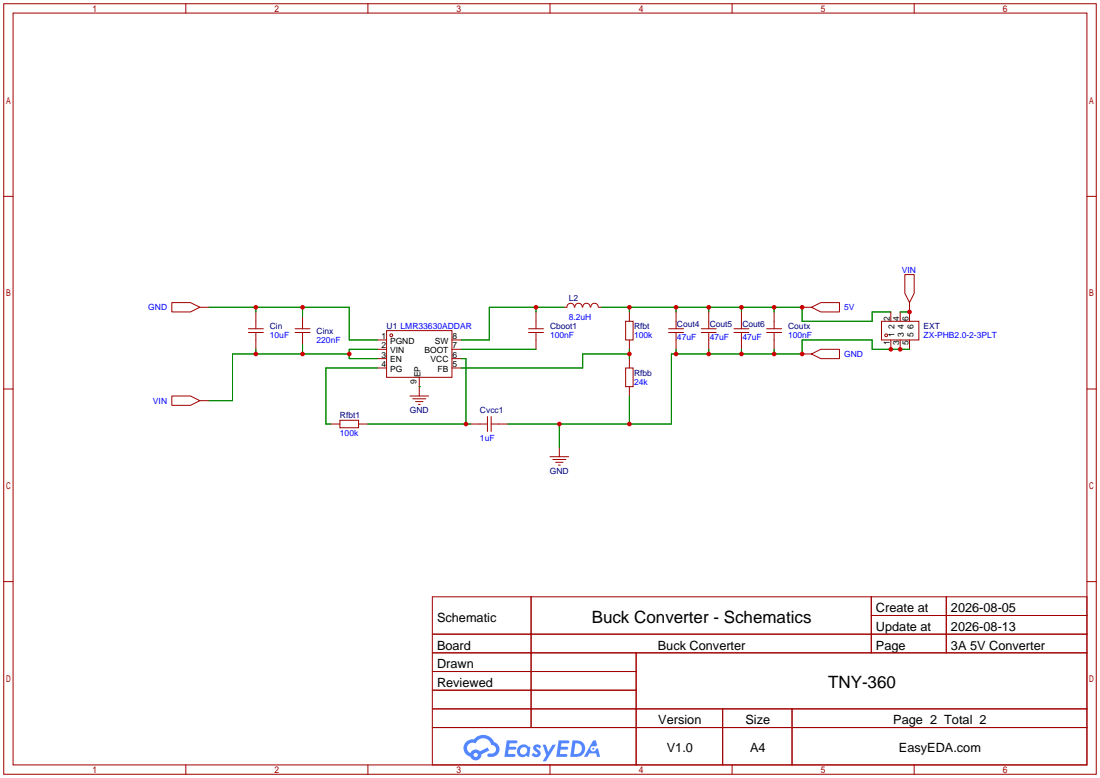
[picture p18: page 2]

Schematic | Buck Converter - Schematics | Create at | 2026-08-05

Update at | 2026-08-13

Board | Buck Converter | Page | 3A 5V Converter
Drawn | | TNY-360
Reviewed

Version | Size | Page 2 Total 2
V1.0 | A4 | EasyEDA.com

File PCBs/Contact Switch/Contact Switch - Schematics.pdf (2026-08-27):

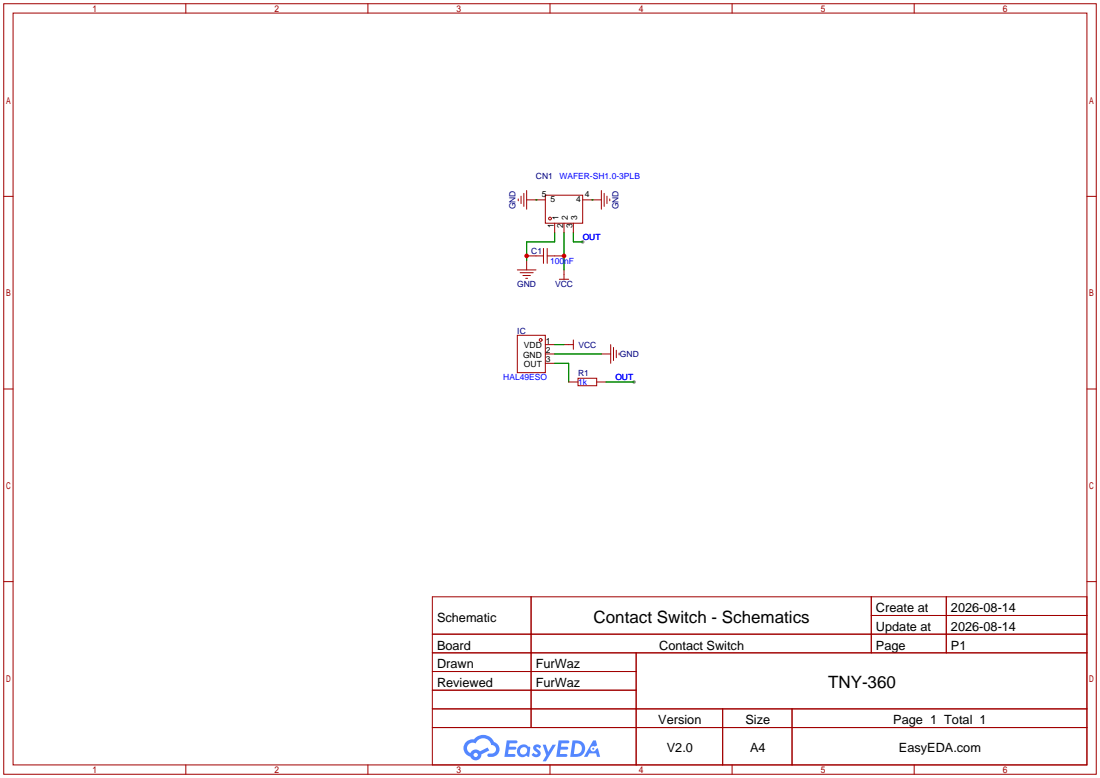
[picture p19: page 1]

Schematic | Contact Switch - Schematics | Create at | 2026-08-14

Update at | 2026-08-14

Board | Contact Switch | Page | P1
Drawn | FurWaz | TNY-360
Reviewed | FurWaz

Version | Size | Page 1 Total 1
V2.0 | A4 | EasyEDA.com

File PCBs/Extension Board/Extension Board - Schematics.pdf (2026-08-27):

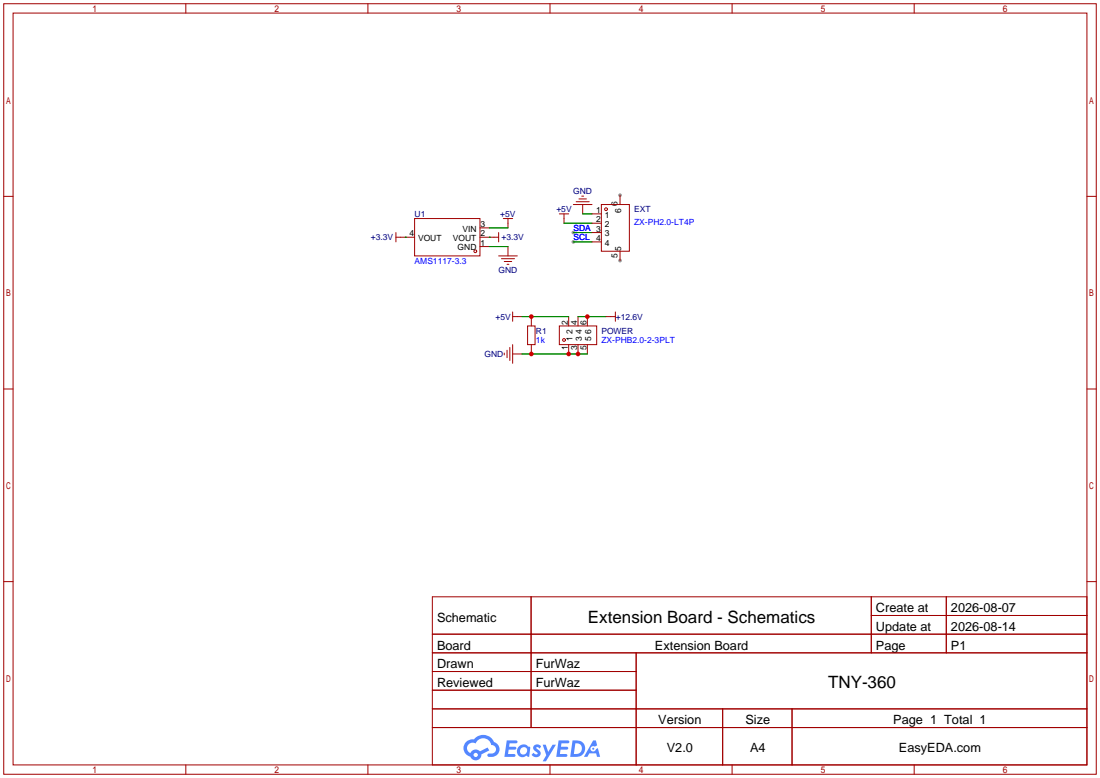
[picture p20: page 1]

Schematic | Extension Board - Schematics | Create at | 2026-08-07

Update at | 2026-08-14

Board | Extension Board | Page | P1
Drawn | FurWaz | TNY-360
Reviewed | FurWaz

Version | Size | Page 1 Total 1
V2.0 | A4 | EasyEDA.com

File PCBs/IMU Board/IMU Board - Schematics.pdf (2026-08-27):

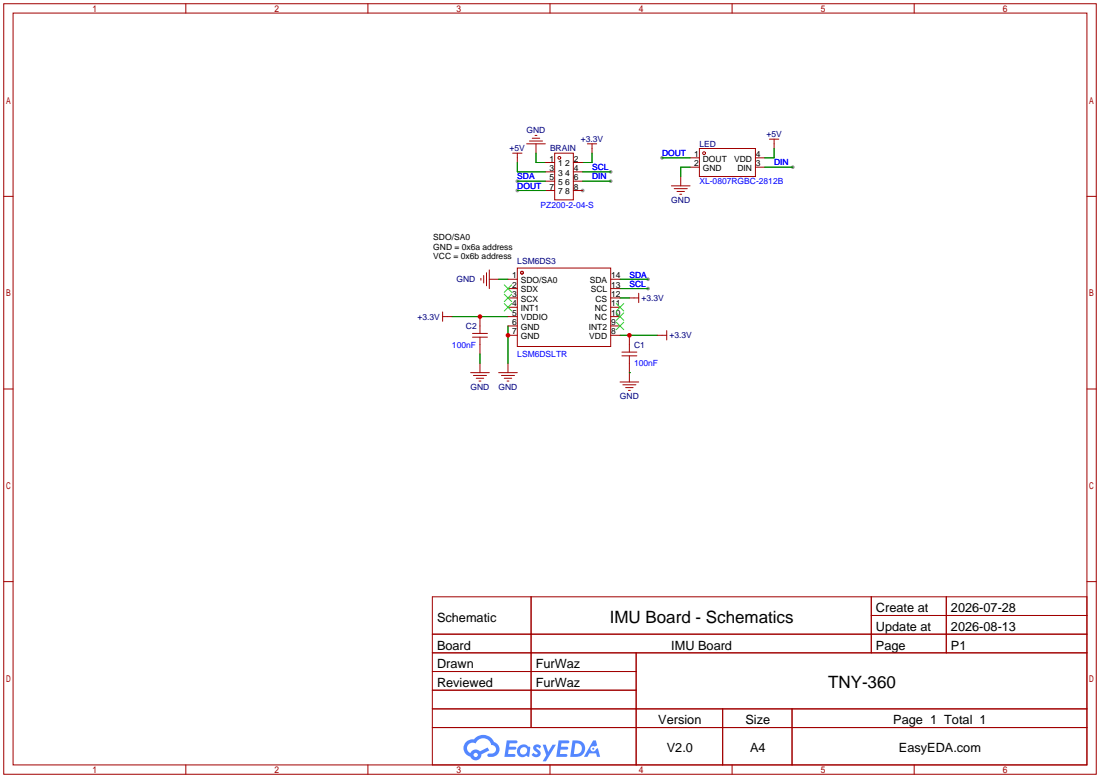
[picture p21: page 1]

NC 10 NC 11 CS 12 SCL 13 SDA 14

Schematic | IMU Board - Schematics | Create at | 2026-07-28

Update at | 2026-08-13

Board | IMU Board | Page | P1
Drawn | FurWaz | TNY-360
Reviewed | FurWaz

Version | Size | Page 1 Total 1
V2.0 | A4 | EasyEDA.com

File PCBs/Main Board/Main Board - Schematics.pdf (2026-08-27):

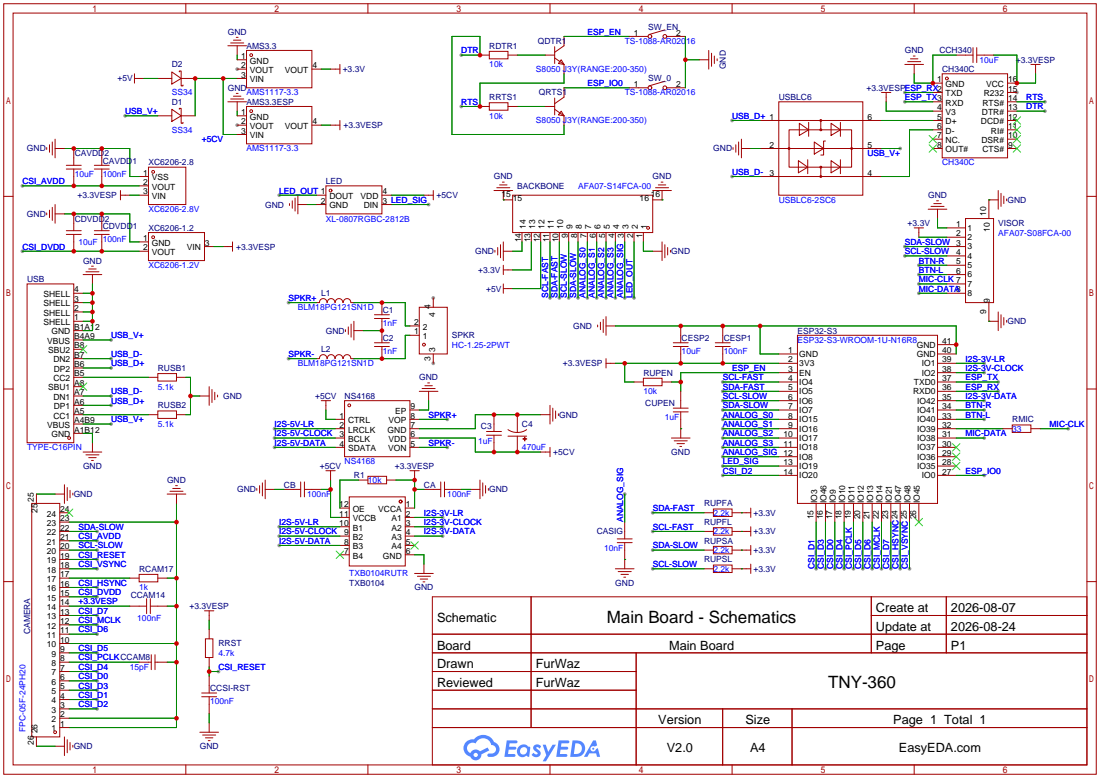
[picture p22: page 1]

DSR# 10 RI# 11 DCD# 12 DTR# 13 RTS# 14 R232 15 VCC 16

GND A1B12 VBUS A4B9 CC1 A5 DP1 A6 DN1 A7 SBU1 A8 CC2 B5 DP2 B6 DN2 B7 SBU2 B8 VBUS B4A9 GND B1A12 SHELL 1

Schematic | Main Board - Schematics | Create at | 2026-08-07

Update at | 2026-08-24

Board | Main Board | Page | P1
Drawn | FurWaz | TNY-360
Reviewed | FurWaz

Version | Size | Page 1 Total 1
V2.0 | A4 | EasyEDA.com

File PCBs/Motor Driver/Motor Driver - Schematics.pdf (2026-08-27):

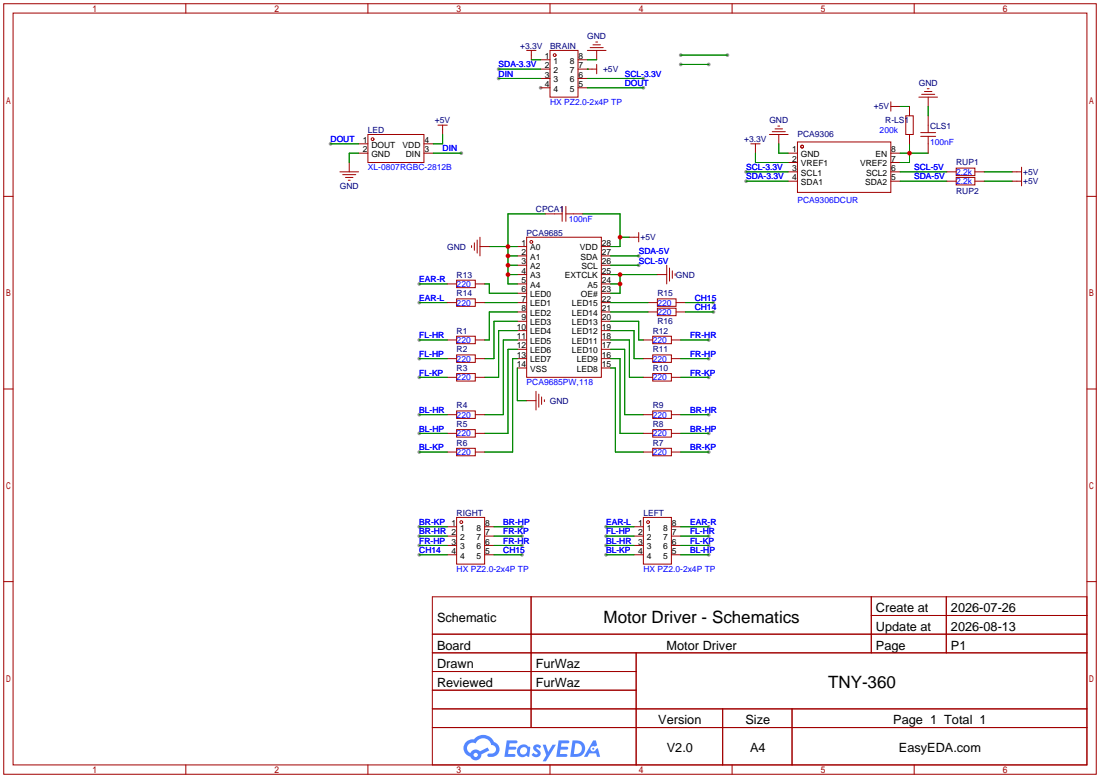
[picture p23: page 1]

Schematic | Motor Driver - Schematics | Create at | 2026-07-26

Update at | 2026-08-13

Board | Motor Driver | Page | P1
Drawn | FurWaz | TNY-360
Reviewed | FurWaz

Version | Size | Page 1 Total 1
V2.0 | A4 | EasyEDA.com

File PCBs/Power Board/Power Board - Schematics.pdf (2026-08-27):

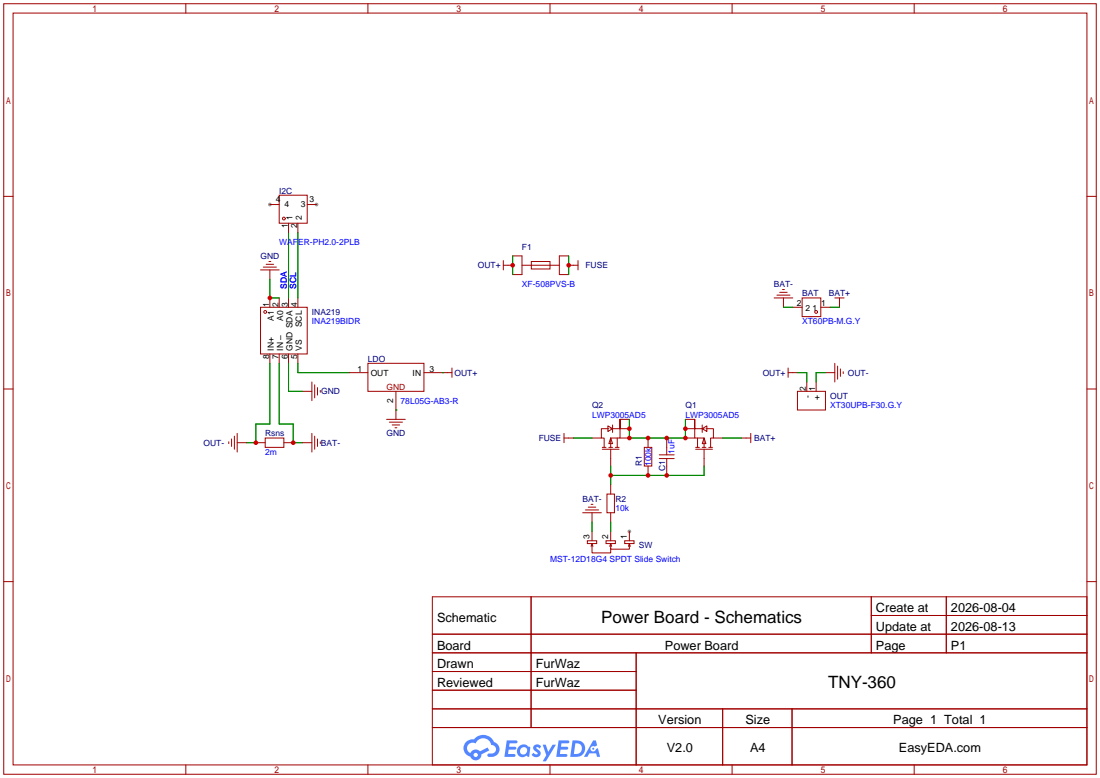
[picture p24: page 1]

MST-12D18G4 SPDT Slide Switch

Schematic | Power Board - Schematics | Create at | 2026-08-04

Update at | 2026-08-13

Board | Power Board | Page | P1
Drawn | FurWaz | TNY-360
Reviewed | FurWaz

Version | Size | Page 1 Total 1
V2.0 | A4 | EasyEDA.com

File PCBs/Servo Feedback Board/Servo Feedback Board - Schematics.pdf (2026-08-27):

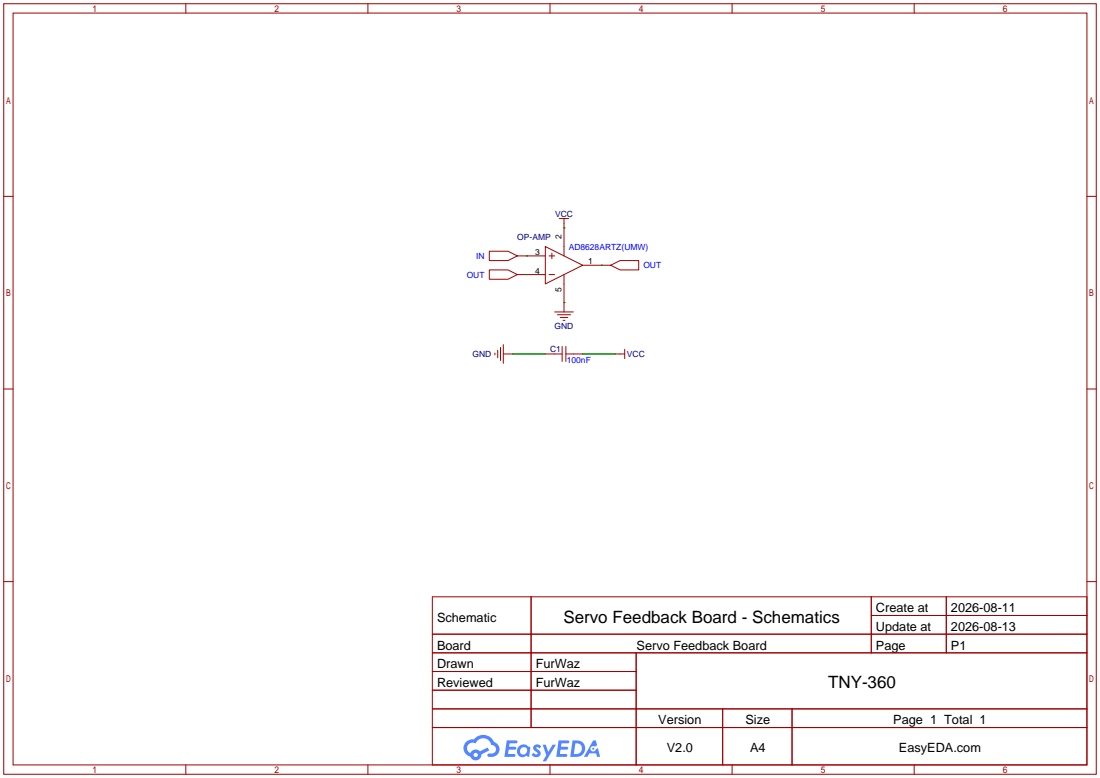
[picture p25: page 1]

Schematic | Servo Feedback Board - Schematics | Create at | 2026-08-11

Update at | 2026-08-13

Board | Servo Feedback Board | Page | P1
Drawn | FurWaz | TNY-360
Reviewed | FurWaz

Version | Size | Page 1 Total 1
V2.0 | A4 | EasyEDA.com

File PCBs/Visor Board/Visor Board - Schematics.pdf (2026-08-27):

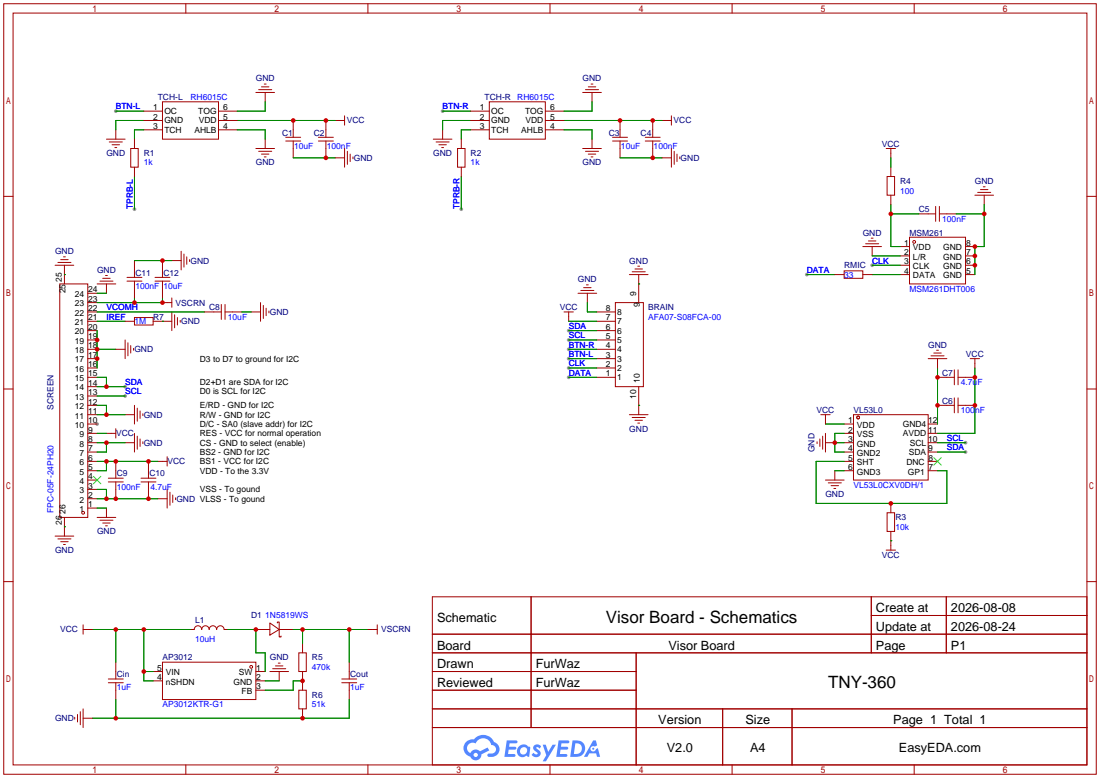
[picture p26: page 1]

D3 to D7 to ground for I2C

D2+D1 are SDA for I2C
D0 is SCL for I2C
E/RD - GND for I2C
D/C - SA0 (slave addr) for I2C
RES - VCC for normal operation
CS - GND to select (enable)
BS2 - GND for I2C
VDD - To the 3.3V
VSS - To gound
GND VLSS - To gound

Schematic | Visor Board - Schematics | Create at | 2026-08-08

Update at | 2026-08-24

Board | Visor Board | Page | P1
Drawn | FurWaz | TNY-360
Reviewed | FurWaz

Version | Size | Page 1 Total 1
V2.0 | A4 | EasyEDA.com

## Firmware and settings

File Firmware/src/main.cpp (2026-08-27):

#include <freertos/FreeRTOS.h>
#include "common/Log.hpp"
#include "Robot.hpp"
#include "common/config.hpp"
#include "common/RPC.hpp"
#include "boot/BootManager.hpp"

static const char* TAG = "Main";

static Robot robot;
CameraDriver cam;
WiFiManager wifi;

#ifdef __cplusplus
extern "C" {
#endif
void app_main()
{
    // Check for special boot state (zero-calibration, pending update, etc.)
    if (BootManager::CheckForSpecialBoot())
    {
        // Special boot state detected.
        // The corresponding boot will be handled by the BootManager.
        // wait forever to avoid booting as normal (should not happen anyway)
        return;
    }

    LOG_INFO(TAG, "Initializing robot (FIRMWARE_VERSION=%s) ...", FIRMWARE_VERSION);

    if (Status err = robot.init(); err != Status::Ok)
    {
        // LOG_ERROR(TAG, "Failed to initialize robot. Error : %s", StatusToString(err));
        return;
    }

    LOG_INFO(TAG, "Robot initialized successfully.");
    
    LOG_INFO(TAG, "Starting robot ...");

    if (Status err = robot.start(); err != Status::Ok)
    {
        // LOG_ERROR(TAG, "Failed to start robot. Error : %s", StatusToString(err));
        return;
    }

    LOG_INFO(TAG, "Robot started successfully !");

    // Nothing to do here

    LOG_INFO(TAG, ">>> Robot is operational.");
}
#ifdef __cplusplus
}
#endif

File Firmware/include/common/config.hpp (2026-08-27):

#pragma once
#include <cstdint>
#include <driver/gpio.h>

/** COMPILATION FLAGS **/
#define DEBUG_MODE 1  // 1 to enable debug logs and behaviors, 0 to disable

/** MULTICORE SETUP */
constexpr int CORE_BRAIN = 0;
constexpr int CORE_REFLEX = 1;
// number of milliseconds before triggering security stop (in case brain core crashes, to clear control intent)
constexpr uint32_t CONTROL_INTENT_WATCHDOG_MS = 500;

/** OTA SETUP **/
constexpr const char* OTA_FIRMWARE_LATEST_URL = "https://api.tny-robotics.com/firmware/latest";
constexpr const char* OTA_FILESYSTEM_DOWNLOAD_URL = "https://cdn.tny-robotics.com/firmware/tny-360/%s/filesystem.bin";
constexpr int OTA_UPDATE_TIMEOUT_MS = 5000;
constexpr int OTA_UPDATE_FILESYSTEM_BUFFER_SIZE = 4096; // in bytes
constexpr const char* OTA_ROBOT_MODEL = "tny-360";


/** PHYSICAL INFORMATIONS **/
constexpr float LEG_THIGH_LENGTH_M = 0.100f; // in meters
constexpr float LEG_CALF_LENGTH_M = 0.100f; // in meters
constexpr float HIP_OFFSET_M = 0.034f; // in meters
constexpr float HIP_POS_X_M = 0.086f; // in meters, from body center
constexpr float HIP_POS_Y_M = 0.052f; // in meters, from body center

/** DEFAULT POSE INFORMATIONS **/
constexpr float DEFAULT_BODY_HEIGHT_M   = 0.120f; // in meters, from ground level
constexpr float DEFAULT_FEET_SPREAD_X_M = 0.090f; // in meters, from body center
constexpr float DEFAULT_FEET_SPREAD_Y_M = 0.100f; // in meters, from body center


/** ERROR EVENTS **/
const int ERROR_MAX_EVENTS = 32;


/** LOGGING **/
// Maximum number of log lines to store
constexpr int LOG_MAX_LINES = 32;
// Maximum length of each log message
constexpr int LOG_MAX_MSG_LEN = 160;
// Maximum length of log tag
constexpr int LOG_MAX_TAG_LEN = 16;

/** FILESYSTEM **/
// Maximum path length for file operations
constexpr int MAX_PATH_LEN = 128;

/** RPC **/
constexpr int RPC_QUEUE_SIZE = 32; // number of pending RPC jobs (between core 0 and core 1)


/** Wi-Fi **/
// Maximum number of connection retries before giving up
constexpr uint8_t WIFI_MAX_RETRIES = 5;
// Maximum length for SSID and Password
constexpr uint8_t WIFI_MAX_SSID_LEN = 32;
constexpr uint8_t WIFI_MAX_PASSWORD_LEN = 64;
// AP SSID and Password
constexpr const char* WIFI_AP_SSID = "TNY-360";
constexpr const char* WIFI_AP_PASSWORD = ""; // open by default


/** Websocket **/
// Maximum message size for WebSocket frames
constexpr uint16_t WEBSOCKET_MAX_MSG_SIZE = 256; // in bytes


/** Protocol **/
// Maximum number of pending protocol commands
constexpr uint8_t PROTOCOL_MAX_PENDING_COMMANDS = 32;
// Maximum number of commands in the protocol
constexpr uint8_t PROTOCOL_MAX_COMMANDS_HANDLERS = 255;


/** I2C **/
// Primary I2C GPIO pins (for critical modules, like sensors)
constexpr gpio_num_t I2C_PRIMARY_SDA_GPIO_NUM = GPIO_NUM_21;
constexpr gpio_num_t I2C_PRIMARY_SCL_GPIO_NUM = GPIO_NUM_47;
// Secondary I2C GPIO pins (for less critical modules, like screens)
constexpr gpio_num_t I2C_SECONDARY_SDA_GPIO_NUM = GPIO_NUM_9;
constexpr gpio_num_t I2C_SECONDARY_SCL_GPIO_NUM = GPIO_NUM_48;


/** Analog Readings **/
// EMA filter alpha value (1.0 = no filtering, 0.1 = big inertia)
constexpr float ANALOG_EMA_ALPHA = 0.05f;

/** Timer management **/
// Control loop frequency
constexpr int CONTROL_LOOP_FREQ_HZ = 200; // Hz
// Resolution of the control loop timer
constexpr int TIMER_RESOLUTION = 1'000'000; // 1Mhz, 1 us
// [][] calculated values below, do not edit manually
constexpr int TIMER_ALARM_COUNT = TIMER_RESOLUTION / CONTROL_LOOP_FREQ_HZ;
constexpr float CONTROL_LOOP_DT_S = 1.0f / CONTROL_LOOP_FREQ_HZ;
constexpr int CONTROL_LOOP_DT_MS = static_cast<int>(CONTROL_LOOP_DT_S * 1000);

// Decision loop frequency
constexpr int DECISION_LOOP_FREQ_HZ = 30; // Hz
constexpr float DECISION_LOOP_DT_S = 1.0f / DECISION_LOOP_FREQ_HZ;
constexpr int DECISION_LOOP_DT_MS = static_cast<int>(DECISION_LOOP_DT_S * 1000);

/** Analog scanner **/
// GPIO pins for the 4-bit multiplexer select lines
constexpr gpio_num_t SCANNER_SLCT_PIN1 = GPIO_NUM_39;
constexpr gpio_num_t SCANNER_SLCT_PIN2 = GPIO_NUM_40;
constexpr gpio_num_t SCANNER_SLCT_PIN3 = GPIO_NUM_41;
constexpr gpio_num_t SCANNER_SLCT_PIN4 = GPIO_NUM_42;


/** LEG **/
// Voltage threshold at which the leg is considered as grounded (touching ground)
constexpr float LEG_GROUNDED_THRESHOLD_V = 2.0f;


/** IMU **/
// I2C address for the IMU (MPU6050)
constexpr uint8_t IMU_I2C_ADDR = 0x68;
// I2C clock speed for IMU communication
constexpr uint32_t IMU_I2C_CLOCK = 400'000; // Hz
// number of samples to gather for calibration
constexpr uint16_t IMU_NB_CALIB_SAMPLES = 100;
// NOTE : Internal robot imu update is driven by the main timer at 200Hz
constexpr float GRAVITY = 9.81f; // m/s^2
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

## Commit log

2025-02-13 Added sh1106 driver submodule
2025-02-13 Added base project and source code for the ESP32
2025-10-04 Started new firmware project (cleaner code, cleaner architecture)
    [partitions.csv]
2025-11-28 Started new ESP32 firmware
2025-11-28 Improved firmware
    Added LED control, started Websocket protocol commands
2025-11-28 Started V2 CAD models
    [Ear_L.FCStd, Ear_L_Back.FCStd, Ear_L_Diffuser.FCStd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]
2025-11-28 Removed manual support
    [Servo_Cover_L.FCStd]
2025-11-28 Added all external models
    [BMS 3S 20A.FCStd, DC-DC Buck 20A.FCStd, I2S Microphone Breakout Board.FCStd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]
2025-11-28 Started left leg assembly
    [Leg_Bottom_L.FCStd, Leg_L.FCStd, Leg_Top_L.FCStd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]
2025-11-28 Fixed wrong mesurements
    [Leg_Bottom_L.FCStd, Leg_L.FCStd, Leg_Top_L.FCStd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]
2025-11-28 Added physical stops
    [Leg_Bottom_L.FCStd, Leg_L.FCStd, Leg_Top_L.FCStd]
2025-11-28 Added better task lifecycle and led error codes
    [config.hpp, main.cpp]
2025-11-29 Added Shoulder FL and Torso Bottom models
    [Full.FCStd, Leg_Bottom_L.FCStd, Leg_Bottom_R.FCStd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]
2025-11-30 Fixed Button module and enabled it
    [main.cpp]
2025-12-06 Finished shoulders design
    [Shoulder_FL.FCStd, Shoulders.FCStd]
2025-12-06 Smoothed part edges for better look
    [Ear_L_Back.FCStd, Ear_L_Diffuser.FCStd, Ear_L_Front.FCStd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]
2025-12-06 Updated and improved torso design
    [Torso_Bottom.FCStd, Torso_Botton.FCStd]
2025-12-06 Updated full robot assembly
    [Full.FCStd]
2025-12-06 Fixed servomotor flower wrong center radius
    [Leg_Bottom_L.FCStd, Leg_Top_L.FCStd]
2025-12-06 Woops forgot to save these files
    [Leg_Top_L.FCStd, Settings.FCStd]
2025-12-07 Removed ESP32 folder (old firmware)
2025-12-07 Added driver links in readme
2026-01-13 Improved CAD models
    [DC-DC Backplate.FCStd, DC-DC Frontplate.FCStd, Full.FCStd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]
2026-01-19 Added torso top plate and improved tolerances
    [Settings.FCStd, Torso.FCStd, Torso_Bottom.FCStd]
2026-01-19 Firmware v2, static class-oriented
    Added motor calibration and full body IK.
2026-01-25 Improved bottom leg (TPU grip + style)
    [Leg_Bottom.FCStd, Leg_Top_R_Deco.FCStd, Torso.FCStd]
2026-01-25 Added custom TNY-360 ESP32 board in project
2026-01-25 Added body calibration, sound [WIP] and OTA update
2026-01-31 Started WebPortal, improved protocol, fixed bugs
    [Joint.hpp, Protocol.cpp]
2026-02-07 Added leg top deco and battery pack models
    [Battery Pack.FCStd, Leg_Top.FCStd, Leg_Top_L_Deco.FCStd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]
2026-02-07 Added IMU support and manual calibration
2026-02-07 modified cad settings
    [Settings.FCStd]
2026-02-10 Fixed bottom leg angle range
2026-02-13 WIP Head
    [Head.FCStd, Head_Backplate.FCStd, Leg_Bottom.FCStd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]
2026-02-14 Changed visor size and fixed small details
    [Head.FCStd, Settings.FCStd]
2026-02-16 Finished Head model V1
    [Head.FCStd]
2026-02-17 Improved head model (Still needs work)
    [Ear_L_Back.FCStd, Settings.FCStd]
2026-02-19 Grouped Ears in one file, and improved head model
    [Ear_L_Back.FCStd, Ear_L_Diffuser.FCStd, Ear_L_Front.FCStd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]
2026-03-05 Uploaded all V1 PCB fabrication files
    [BOM.xlsx, PickAndPlace.xlsx]
2026-03-06 Added PCB link to readme
2026-03-07 Added joint markings for easier assembly
    [Leg_Bottom.FCStd, Leg_Top.FCStd, Settings.FCStd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]
2026-03-07 Added text on leg top models
    [Leg_Top.FCStd, Settings.FCStd]
2026-03-07 Added text markings to leg bottom
    [Leg_Bottom.FCStd]
2026-03-07 Added text markings on Shoulders
    [Shoulders.FCStd]
2026-03-10 Added Menu system and started Camera integration + 200hz control
    Also improved a lot the web interface*
2026-03-13 Firmware refactor + 200Hz dualcore control loop
2026-03-16 Added new clip system to leg bottom
    [Leg_Bottom.FCStd, Master_Clip.FCStd]
2026-03-17 Added clip system to leg top
    [Leg_Bottom.FCStd, Leg_Top.FCStd, Master_Clip.FCStd]
2026-03-22 Added the entire robot BOM
2026-03-27 Fixed 3D models + side-hole compensation
    [Head.FCStd, Leg_Bottom.FCStd, Leg_Top.FCStd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]
2026-03-31 Updated BOM links and lists
2026-04-09 [WIP] Exported STL parts
    [Back - Bottom Clip.stl, Back - Cover.stl, Battery - LipoHolder Base.stl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]
2026-04-19 Fixed 3d models clearances and other things
    [Head - Bottom Cover.stl, Head - Top Cover.stl, Head - Visor Plate.stl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]
2026-04-20 Added Missing Torso Wing L & R
    [Torso - Cover Wing L.stl, Torso - Cover Wing R.stl, Torso - Cover Wing.stl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]
2026-04-29 Fixed network problems (Captive Portal + QRCode)
    [Protocol.cpp]
2026-05-10 Finished startup calibration menu & fixed details
2026-05-11 Updated Analog Reader to V1.1
    Added analog filtering (4.7kOhms res + 1uF cap) on all inputs
    [BOM.xlsx, PickAndPlace.xlsx]
2026-05-11 Added analog filtering and fixed audio noise
    [BOM.xlsx, PickAndPlace.xlsx]
2026-05-13 Fixed start calibration collisions
    [Joint.hpp]
2026-05-21 Added commands, fixed overrides, + power menu
    [config.hpp]
2026-06-09 Squashed commit of the following:
    commit 9628480599c2806fdfe26e940fc00197511a99c6
    Author: Paul LOISIL <fur.waz06@gmail.com>
    Date: Tue Jun 9 09:14:24 2026 +0200
    Added Gauge and Test parts in .3mf file
    commit fc86d56d35d1d1f83f7fb5a86db83fd5a17f7720
    Author: Paul LOISIL <fur.waz06@gmail.com>
    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
    [Leg_Top.FCStd, Master_Clip.FCStd, Settings - ClipTester.stl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]
2026-06-10 Squashed commit of the following:
    commit c5b9480114d783ad99229b1ce3a12848e49040f0
    Date: Wed Jun 10 15:38:06 2026 +0200
    Fixed slight tilt in [Leg-Top Deco Bottom L] part
    Date: Tue Jun 9 09:13:49 2026 +0200
    Added calibration in web dashboard
    commit 612b617246c655281911d42e40f954cc35de3672
    Date: Mon Jun 8 15:34:46 2026 +0200
    Incre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
    [Leg - Top Cover Bottom L.stl]
2026-06-12 Added supports and gauge / calibration parts
2026-07-06 Added new diagnostic/calib mode + error events
    [Diagnostic.cpp]
2026-07-06 Fixed upper case file
2026-07-12 Added smoothEnable/Disable + other fix
    - Fixed MotorController constructor logic
    - Set Max Joint Velocity to a real value
    - Fixed deinit typo
    - Switched to 240Mhz instead of 160MHz only
    [Joint.hpp, main.cpp]
2026-08-24 Added D3 diode warning on Main Board
2026-08-27 Squashed commit of the following:
    commit c8cbeb114f5433ccef268d0711eeeede07aefa27
    Date: Thu Aug 27 21:43:00 2026 +0200
    Removed unused settings config fields
    commit b26b91e13c12c0e1351127cc8f97bbbaf1a28484
    Date: Thu Aug 27 21:38:14 2026 +0200
    Disabled speaker (audio not used yet)
    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
    [Analog Reader - BOM.csv, Analog Reader - PickAndPlace.csv, BOM.xlsx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]

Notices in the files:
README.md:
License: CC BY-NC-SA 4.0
